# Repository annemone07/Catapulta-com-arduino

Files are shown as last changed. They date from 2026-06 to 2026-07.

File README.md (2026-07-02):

//PT-BR//

Esse projeto foi desenvolvido por alunos de graduação do primeiro período em Engenharia da Computação do CIn - UFPE. Abaixo estão alguns comentários e observações para aqueles que se interessarem em replicar o projeto.

//PEÇAS//
As peças da montagem já estão nos arquivos para impressão/corte à laser. Todas as peças de impressão foram feitas com PLA e preenchimento de giroide. Todas as peças, exceto a barra lateral, foram impressas com densidade de 15%. Já a barra lateral foi impressa com densidade 20% e "em pé" para aumentar a resistência mecânica. Diversas partes foram lixadas em momentos da montagem, sendo recomendado o seu uso para facilitar o encaixe e a movimentação mecânica(podendo ser feito de modo manual ou com micro retifica). A alavanca foi cortada em acrílico com espessura de 3mm.

//ENCAIXES//
Para os parafusos que não são dos servos, foi utilizado a base de M3. É recomendado, para a fixação das partes que vão diretamente nos servos(alavanca do elástico e base superior) o uso de cola super bonder, utilizando os buracos como referência. A alavanca possui 4 buracos, distando 5, 4, 3 e 2 cm do centro da mesma, a depender da voltagem de operação e elástico utilizado, sendo relevante realizar tais análises de antemão para não perder alguma peça. Existe um buraco para fixação do cilindro na catapulta, porém não se tornou necessário na execução feita, servindo como ponto de referência para o alinhamento. Partes que eventualmente estejam mal presas podem ser melhor fixadas utilizando super bonder. O elástico utilizado não possuí especificações bem determinadas, sendo relevante o teste e busca de opções.

//COMPONENTES//

2x Botão

2x Micro Servo motor 9g SG90

1x Micro Servo motor MG90

1x LCD I2C

1x Switch

1x Potenciômetro

//OBSERVAÇÕES IMPORTANTES//
Podem existir pequenas variações no tamanho dos servos a depender do fabricante. Caso ache relevante e possua o conhecimento, é válido alterar as medidas dos encaixes para evitar o uso de colas ou retrabalho. É recomendado o uso de uma fonte externa entre 5-5.5V para alimentar os servos, pois conexões diretas no arduino podem causar problemas de operação. LCD pode ser conectado na saída de 5V do arduino diretamente.

//EN//

This project was developed by first semester graduates of Computer Engineering at CIn - UFPE. Listed below are some comments and observations for those who want to replicate the project.

//PARTS//
The parts are already on the file called "partes". Everything done by 3D printing was made with PLA and gyroid filling. All of the 3D printed pieces, but the side bar("barra lateral"), had 15% density filling. The side bar had 20% filling and was printed in the same orientation as it is placed in the assembly, because it guarantees more mechanical endurance. Many parts were sanded during the assembly, being a recommendation to make things fit better and the movement cleaner(the sanding can be done manually or using a rotary tool). The lever("alavanca") was cut in acrylic with 3mm of thickness.

//ASSEMBLY//
For the screws that do not fit in the servos, was used M3. It is recommended, when fixing the parts that go directly in the servos(the lever and superior base) the use of super bonder glue, using the holes as reference. The lever has 4 holes, distancing 5, 4, 3 and 2 cm from the center, depending of the voltage used in the servo system and the elastic, being relevant test things before permanently fixing the things. There is a hole in the catapult's cylinder to fix, but it did not make it self necessary, just being used as an reference to align. Parts that might be loose, can be better fixed using super bonder glue. The elastic does not have any specifications, being indicated testing and options.

//COMPONETS//

2x Buttons

2x Micro Servo motor 9g SG90

1x Micro Servo motor MG90

1x LCD I2C

1x Switch

1x Potentiometer

//IMPORTANT OBSERVATIONS//
There may be slightly divergences on the servo sizes depending of the manufacturer. If you find relevance and have the knowledge, it is valid to change the fitting sizes, trying to avoid glue or rework. It is recommended the use of an external power source, between 5-5.5V to feed the servos, because direct connections might cause operational issues. The LCD can be powered directly in the 5V output of the arduino.

//CIRCUITO(CIRCUIT)//

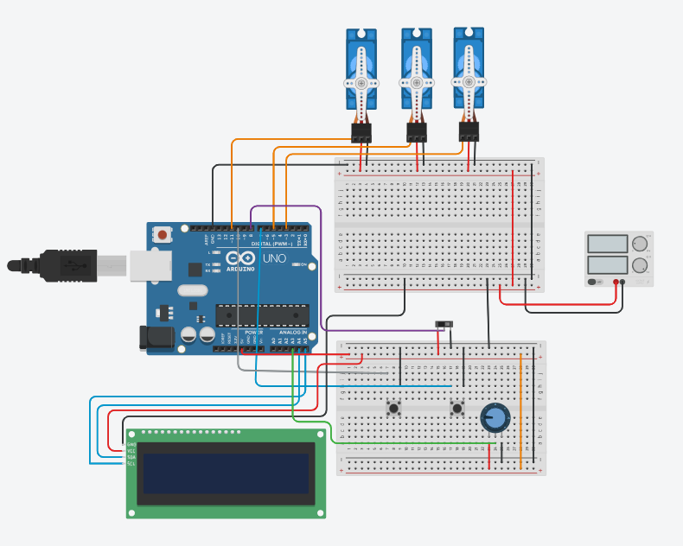
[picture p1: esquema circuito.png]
Circuito esquemático


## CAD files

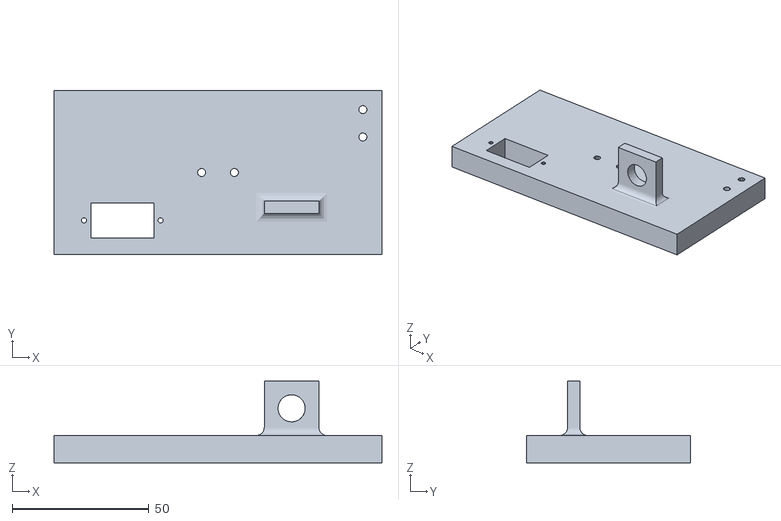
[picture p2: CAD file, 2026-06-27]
pecas/base superior.stl
120.0 x 60.0 x 30.0

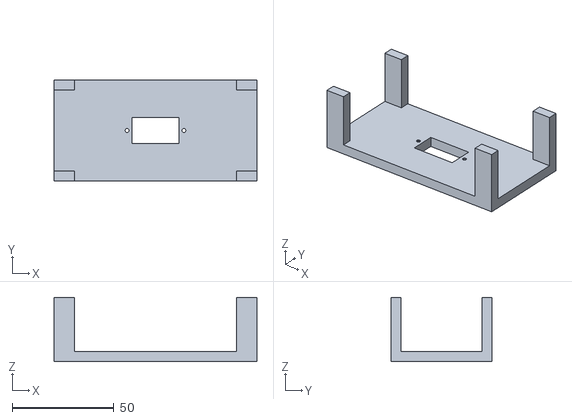
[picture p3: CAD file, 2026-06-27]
pecas/base principal.stl
100.0 x 50.0 x 31.6

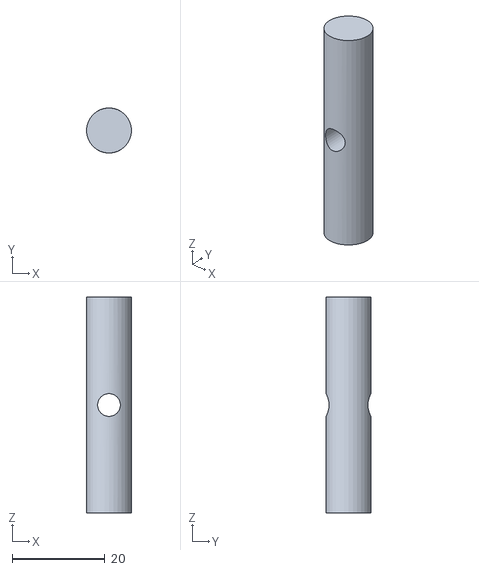
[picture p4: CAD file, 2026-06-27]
pecas/cilindro catapulta.stl
9.70 x 9.70 x 46.5

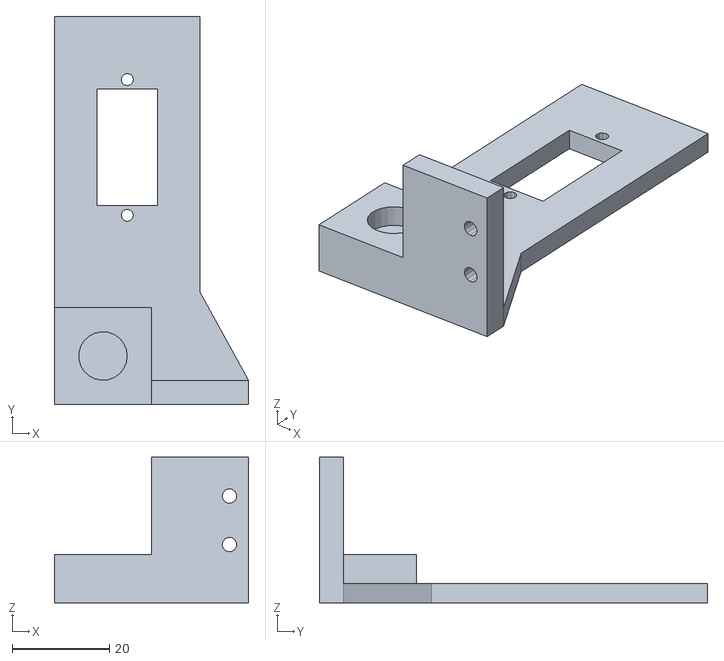
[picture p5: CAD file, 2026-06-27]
pecas/barra lateral.stl
40.0 x 80.0 x 30.0

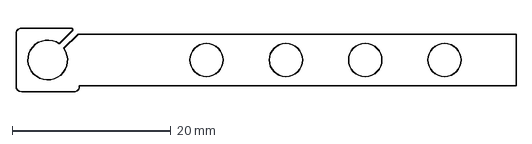
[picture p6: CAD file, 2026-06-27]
pecas/alavanca elastico.dxf
63.0 x 8.00 mm

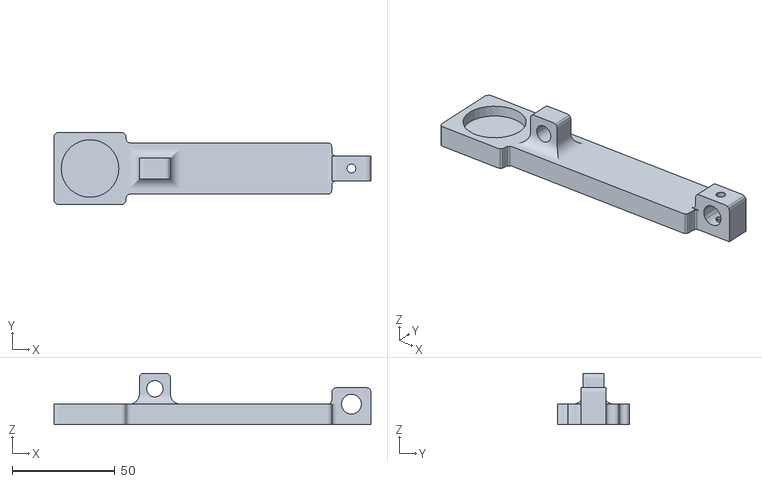
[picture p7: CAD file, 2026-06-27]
pecas/catapulta.stl
154.0 x 35.0 x 25.0

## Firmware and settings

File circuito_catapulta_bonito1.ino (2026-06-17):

#include <LiquidCrystal_I2C.h>
#include <Servo.h>
//#include <pitches.h>
#define servoPuxarLancador 3
#define servoTrava 5
/*
#define motorGiroLigar 13
#define motorGiroPos 11
#define motorGiroNeg 10
*/
#define servoGiro 11
#define motorAlvoLigar 13
#define motorAlvoPos 6
#define motorAlvoNeg 9
#define botao 7
#define botaoAlvo 10
#define switchLancamento 8
#define buzzer 2
/*#define RS 23
#define En 22
#define db4 24
#define db5 25
#define db6 26
#define db7 27
*/

LiquidCrystal_I2C lcd(0x20, 16, 2);
Servo servoPuxador;
Servo servoGirador;
Servo travaCatapulta;
int contadorPosServo=0;
bool ladoGiro=true;
bool ladoAlvo=true;
bool lancando=false;
bool botaoLancamentoApertado=false;

int pontos=0;
String dificuldade = "nao";
void setup()
{
  Serial.begin(9600);
  //lcd_1.begin(16, 2);
  pinMode(botao, INPUT_PULLUP);
  pinMode(botaoAlvo, INPUT_PULLUP);
  pinMode(switchLancamento,INPUT);
  pinMode(servoPuxarLancador,OUTPUT);
  pinMode(servoTrava,OUTPUT);
  pinMode(servoGiro,OUTPUT);
  pinMode(motorAlvoLigar,OUTPUT);
  pinMode(motorAlvoPos,OUTPUT);
  pinMode(motorAlvoNeg,OUTPUT);
  pinMode(buzzer, OUTPUT);
  //pinMode(RS,OUTPUT);
  pinMode(En,OUTPUT);
  //pinMode(db4,OUTPUT);
  //pinMode(db5,OUTPUT);
  //pinMode(db6,OUTPUT);
  //pinMode(db7,OUTPUT);
  digitalWrite(motorAlvoLigar, HIGH);
  lcd.init();
  lcd.backlight();
}

int tempoLancamento = millis();
bool updateTempoLancamento = true;
String dif[3] = {"Facil", "Medio", "Dificil"};
int i = 0;
int tempoBotao = 0;
bool apertou = 0;
bool valorBotao = 0;
int velocidade=0;
void loop()
{
  unsigned long tempoInicialDificuldade=millis();
  lcd.print("Selecione: ");
  lcd.setCursor(0, 1);
  lcd.print("Facil");
  while(dificuldade == "nao"){
    lcd.setCursor(0, 0);
    valorBotao = !digitalRead(botao);
    while(valorBotao){
      tempoBotao+=1;
      delay(1);
      apertou=true;
      valorBotao = !digitalRead(botao);
    }
    /*if(!valorBotao){
      if (millis()-tempoInicialDificuldade<2000){
        lcd.clear();
        lcd.print("Selecione: ");
        lcd.setCursor(0, 1);
      	lcd.print(dif[0]);
      }
      else if (millis()-tempoInicialDificuldade<4000){
        lcd.clear();
        lcd.print("Selecione: ");
        lcd.setCursor(0, 1);
      	lcd.print(dif[1]);
      }
      else if (millis()-tempoInicialDificuldade<6000){
        lcd.clear();
        lcd.print("Selecione: ");
        lcd.setCursor(0, 1);
      	lcd.print(dif[2]);
      }
      else{
      	tempoInicialDificuldade=millis();
      }
      apertou = 0;
    }
    while(valorBotao){
      tempoBotao = millis() + 1000;
      apertou = 1;
    }
    */
    if(apertou){
      apertou=false;
      if(tempoBotao <= 1000){
        tempoBotao = 0;
        i = i + 1;
        if(i==3){
          i = 0;
        }
        lcd.clear();
        lcd.print("Selecione: ");
        lcd.setCursor(0, 1);
        lcd.print(dif[i]);
      }
      else{
        dificuldade = dif[i];
      }
    }
  }
  Serial.println("saiu");
  lcd.clear();
  lcd.home();
  lcd.print("Dificuldade: ");
  lcd.setCursor(0, 1);
  lcd.print(dificuldade);
  delay(2000);
  lcd.clear();
  lcd.home();
  lcd.print("Pontuacao: 0");
  lcd.setCursor(0, 1);
  lcd.print("Dificuldade: ");
  lcd.print(dificuldade[0]);
  
  while(dificuldade != "nao"){ 
    if(dificuldade==dif[0]){
      velocidade=128;
    }
    else if(dificuldade==dif[1]){
      velocidade=200;
    }
    else{
      velocidade=255;
    }
    //Serial.print("loop");
    servoPuxador.attach(servoPuxarLancador);
    servoGirador.attach(servoGiro);
    travaCatapulta.attach(servoTrava);
    //valorBotao = 0;
    bool travaSwitch = 0, valorBotaoAlvo = 0;
    valorBotao = !digitalRead(botao);
	valorBotaoAlvo = !digitalRead(botaoAlvo);
    travaSwitch = digitalRead(switchLancamento);
    //Serial.println(valorBotao);
    Serial.println(valorBotao);
    
    if (valorBotaoAlvo){
      tone(buzzer, 800, 300);
      pontos+=1;
      lcd.clear();
      lcd.home();
      lcd.print("Pontuacao: ");
      lcd.print(pontos);
      lcd.setCursor(0, 1);
      lcd.print("Dificuldade: ");
      lcd.print(dificuldade[0]);
    }
    
    if(travaSwitch){
      if (valorBotao){
        botaoLancamentoApertado=true;
      }
      if(botaoLancamentoApertado){
        if(updateTempoLancamento){
          updateTempoLancamento=false;
          tempoLancamento=millis();
        }
        Serial.print("pontos ");
        Serial.println(pontos);
        valorBotaoAlvo=!digitalRead(botaoAlvo);
        if(millis()-tempoLancamento<2000){
          contadorPosServo = constrain(contadorPosServo,0,180);
          servoGirador.write(contadorPosServo);
          analogWrite(motorAlvoPos, 0);
          lancar();
          travaCatapulta.write(180);
        }
        else if (millis()-tempoLancamento<4000){
          lancando=false;
        }
        else if (millis()-tempoLancamento<6000){
          servoPuxador.write(0);
        }
        else if (millis()-tempoLancamento<8000){
          travaCatapulta.write(0);
        }
        else{
          botaoLancamentoApertado=false;
          analogWrite(motorAlvoPos, 255);
          delay(20);
        }
      }
      else if (!lancando){
        Serial.print("a");
        moverAlvo(velocidade);
        arrumar();
        girar();
      }

    }
    else{
      Serial.print("noy");
      moverAlvo(velocidade);
      arrumar();
      girar();
      if (valorBotao){
        lcd.clear();
        lcd.home();
        lcd.print("Trava acionada");
        delay(250);
        lcd.clear();
      	lcd.home();
      	lcd.print("Pontuacao: ");
      	lcd.print(pontos);
      	lcd.setCursor(0, 1);
      	lcd.print("Dificuldade: ");
      	lcd.print(dificuldade[0]);
      }
    }
  }
}

void moverAlvo(int velocidadeMotor)
{ //o uso da biblioteca do servo inibe pwm nas portas 9 e 10 --> motivo do problema
  //Serial.println(velocidadeMotor);
  analogWrite(motorAlvoPos, velocidadeMotor);
  analogWrite(motorAlvoNeg, 0);
  
}

void girar()
{
  //ativa motorGiro
  //digitalWrite(motorAlvoLigar, HIGH);
  int t0 = millis()%3000;
  //Serial.println(contadorPosServo);
  if(t0<1500){
    contadorPosServo+=1;
    contadorPosServo = constrain(contadorPosServo,0,180);
  	servoGirador.write(contadorPosServo);
    //if(contadorPosServo==180){
    //  ladoGiro=false;    
    //}
  }
  else{
    contadorPosServo-=1;
    contadorPosServo = constrain(contadorPosServo,0,180);
  	servoGirador.write(contadorPosServo);
    //if(contadorPosServo==0){
    //  ladoGiro=true;    
    //}
  }
}

void lancar()
{
  lancando=true;
  analogWrite(motorAlvoPos, 0); // deixar parando o movimento do alvo durante o lançamento?
  analogWrite(motorAlvoNeg, 0);
  servoPuxador.write(180);
}

void arrumar()
{
  updateTempoLancamento=true;
  travaCatapulta.write(0);
  servoPuxador.write(180);
}

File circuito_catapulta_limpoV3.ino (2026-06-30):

#include <LiquidCrystal_I2C.h>
#include <Servo.h>
//definindo os pinos que serão usados
#define servoPuxarLancador 3
#define servoTrava 5
#define servoGiro 11
#define botao 7
#define botaoRecarregar 10
#define switchLancamento 8
#define potMexer A3
//valores para o movimento do servo do elástico
int valorTensionado = 80;
int valorDestensionado = 180;
int arcoAngulo = 90;
int anguloTravado = 180;
int anguloDestravado = 90;
//variaveis para o print do lcd
int angForm = 0;
int valorAnt = 1024;
LiquidCrystal_I2C lcd(0x27, 16, 2);
//definição dos servos
Servo servoPuxador;
Servo servoGirador;
Servo travaCatapulta;

int contadorPosServo=45;
bool lancando=false;
bool botaoLancamentoApertado=false;
bool cont2;
String mod = "nao"; //variavel para o loop de escolher o modo

void setup() 
{
  pinMode(botao, INPUT_PULLUP);
  pinMode(botaoRecarregar, INPUT_PULLUP);
  pinMode(switchLancamento,INPUT_PULLUP);
  pinMode(servoPuxarLancador,OUTPUT);
  pinMode(servoTrava,OUTPUT);
  pinMode(servoGiro,OUTPUT);
  lcd.init();
  lcd.backlight();
  servoPuxador.write(valorDestensionado);
  servoPuxador.attach(servoPuxarLancador);
  servoGirador.write(arcoAngulo/2);
  servoGirador.attach(servoGiro);
  travaCatapulta.write(anguloTravado);
  travaCatapulta.attach(servoTrava);
}

unsigned long tempoLancamento = millis();
bool updateTempoLancamento = true;
String modos[2] = {"Automatico", "Manual"};
int i = 0;
int tempoBotao = 0;
bool apertou = 0;
bool valorBotao = 0;
bool recarregando=0;
int velocidade=0;
void loop()
{
  unsigned long tempoInicialDificuldade=millis();
  lcd.print("Selecione: ");
  lcd.setCursor(0, 1);
  lcd.print(modos[0]);
  while(mod == "nao"){
    lcd.setCursor(0, 0);
    valorBotao = !digitalRead(botao);
    while(valorBotao){
      tempoBotao+=1;
      delay(1);
      apertou=true;
      valorBotao = !digitalRead(botao);
    }
    
    if(apertou){
      apertou=false;
      if(tempoBotao <= 200){
        tempoBotao = 0;
        i = i + 1;
        if(i==2){
          i = 0;
        }
        lcd.clear();
        lcd.print("Selecione: ");
        lcd.setCursor(0, 1);
        lcd.print(modos[i]);
      }
      else{
        mod = modos[i];
      }
    }
  }
  lcd.clear();
  lcd.home();
  lcd.print("Modo: ");
  if(mod == "Automatico"){
  lcd.setCursor(0, 1);
  lcd.print(mod);
  }
  else if(mod == "Manual"){
  lcd.print(mod);
  lcd.setCursor(0, 1);
  lcd.print("Angulo: ");
  }
  delay(2000);
  
  while(mod != "nao"){ //apos selecionar o modo
    bool travaSwitch = 0, valorBotaoRecarregar = 0;
    valorBotao = !digitalRead(botao);
	  valorBotaoRecarregar = !digitalRead(botaoRecarregar);
    travaSwitch = !digitalRead(switchLancamento);
    
    if(travaSwitch){
      if (valorBotao){
        botaoLancamentoApertado=true;
      }
      if(botaoLancamentoApertado){
        if(updateTempoLancamento){
          cont2=0;
          updateTempoLancamento=false;
          tempoLancamento=millis();
          if(mod == "Automatico"){
            lcd.clear();
            lcd.setCursor(0, 0);
            lcd.print("Modo: Auto");
          }
          lcd.setCursor(0, 1);
          lcd.print("Angulo: ");
          lcd.print(angForm);
        
        }
        valorBotaoRecarregar=!digitalRead(botaoRecarregar);
        
        if (millis()-tempoLancamento<4000){ //puxar tensão
            servoPuxador.write(valorTensionado);
        }
        else if(millis()-tempoLancamento<6000){ //destravar trava
          lancando=true;
          travaCatapulta.write(anguloDestravado);
        }
        else if (millis()-tempoLancamento<8000){ //desligar estado de lançamento
          lancando=false;
        }
        else if (millis()-tempoLancamento<10000){ //ciclo destensionar
          servoPuxador.write(valorDestensionado);
          recarregando=1;
        }
        else if (recarregando){ //ciclo retravar/recarregar
          if(!cont2){
            lcd.clear();
            cont2=1;
            lcd.home();
            lcd.print("Apos recarregar");
            lcd.setCursor(0, 1);
            lcd.print("aperte o botao");
          }
          if (valorBotaoRecarregar){
            valorBotaoRecarregar = !digitalRead(botaoRecarregar);
            travaCatapulta.write(anguloTravado);
            recarregando=0;
          }

        }
        else{
          updateTempoLancamento=true;
          botaoLancamentoApertado=false;
          delay(5000); //temp
          travaCatapulta.write(anguloTravado); //temp
          lcd.clear();
          lcd.home();
          lcd.print("Modo: ");
          if(mod == "Automatico"){
            lcd.setCursor(0, 1);
            lcd.print(mod);
          }
          else if(mod == "Manual"){
            lcd.print(mod);
            lcd.setCursor(0, 1);
            lcd.print("Angulo: ");
          }
        }
      }
      else if (!lancando){
        arrumar();
        girar();
      }

    }
    else{
      arrumar();
      girar();
      if (valorBotao){
        lcd.clear();
        lcd.home();
        lcd.print("Trava acionada");
        delay(250);
        lcd.clear();
        lcd.home();
        lcd.print("Modo: ");
        lcd.print(mod);
      }
    }
  }
}


void girar()
{
  if (mod == "Automatico"){
  int t0 = millis()%3000;
  if(t0<1500){
    contadorPosServo+=1;
    contadorPosServo = constrain(contadorPosServo,0,90);
  	servoGirador.write(contadorPosServo);
  }
  else{
    contadorPosServo-=1;
    contadorPosServo = constrain(contadorPosServo,0,90);
  	servoGirador.write(contadorPosServo);
  }
  angForm = map(contadorPosServo, 0, 90, -45, 45);
  }
  else if (mod == "Manual"){
    int valorPot = analogRead(potMexer);
    int ang = map(valorPot, 0, 1023, 0, 90);
    servoGirador.write(ang);
    if(valorPot != valorAnt){
    valorAnt = valorPot;
    angForm = map(ang, 0, 90, -45, 45);
    lcd.setCursor(8, 1);
    lcd.print(angForm);
    if(angForm >= 0){
      lcd.print(" ");
    }
    }
    
    
  }
  
}


void arrumar()
{
  travaCatapulta.write(anguloTravado);
  servoPuxador.write(valorDestensionado);
}

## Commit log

2026-06-27 código limpo
    código limpo, com remoção de partes inutilizadas e comentários inúteis, organização geral
2026-06-27 peças em stl e dxf
    [alavanca elastico.dxf, barra lateral.stl, base principal.stl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]
2026-06-27 add esquema do circuito
2026-06-27 Update README.md
    add imagem do circuito
